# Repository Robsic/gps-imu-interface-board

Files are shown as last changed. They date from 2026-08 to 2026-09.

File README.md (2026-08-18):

# Placa GPS/IMU e interface de encoders — RobSIC

Placa de aquisição e comunicação para o carrinho elétrico RobSIC, baseada em módulo STM32F103/Blue Pill. O hardware integra alimentação de 12 V, interface CAN, duas entradas de encoder incremental diferencial A/B/Z, conexão para módulo IMU, conexão para módulo GPS e interfaces de programação/depuração.

> **Status:** projeto em desenvolvimento e **não liberado para fabricação**. O relatório DRC fornecido registra 20 violações: 12 de máscara de solda, 5 de clearance, 1 texto espelhado e 2 conflitos de silk sobre cobre.

> **Simulação funcional:** a integração GPS/NMEA, UART, pacote ACEINNA `e2`, CRC e estímulos de IMU/encoders foi exercitada no Proteus 9.1. CAN, desempenho dos sensores reais e comportamento elétrico permanecem pendentes de bancada.

## Arquitetura

```mermaid
flowchart TD
    PWR["12 V — J1"] --> DCDC["TSR2-2450 — 5 V"]
    DCDC --> LDO["LM1117-3.3 — 3,3 V"]
    LDO --> MCU["Blue Pill / STM32F103"]
    CAN["CANH/CANL — J1"] <-->|"SN65HVD230"| MCU
    ENC["2 encoders A/B/Z"] -->|"TVS + AM26LV32"| MCU
    MCU <-->|"UART"| IMU["Módulo IMU — J5"]
    IMU <-->|"UART2"| GPS["Módulo GPS — J4"]
```

## Simulação e validação no Proteus

O ensaio utiliza duas Blue Pills:

- `U1`: controlador principal da placa;
- `U2`: emulador funcional do OpenIMU300ZI;
- `VGPS`: fonte de mensagens NMEA;
- dois terminais virtuais para observar o NMEA a 9600 baud e o diagnóstico da U1 a 115200 baud.

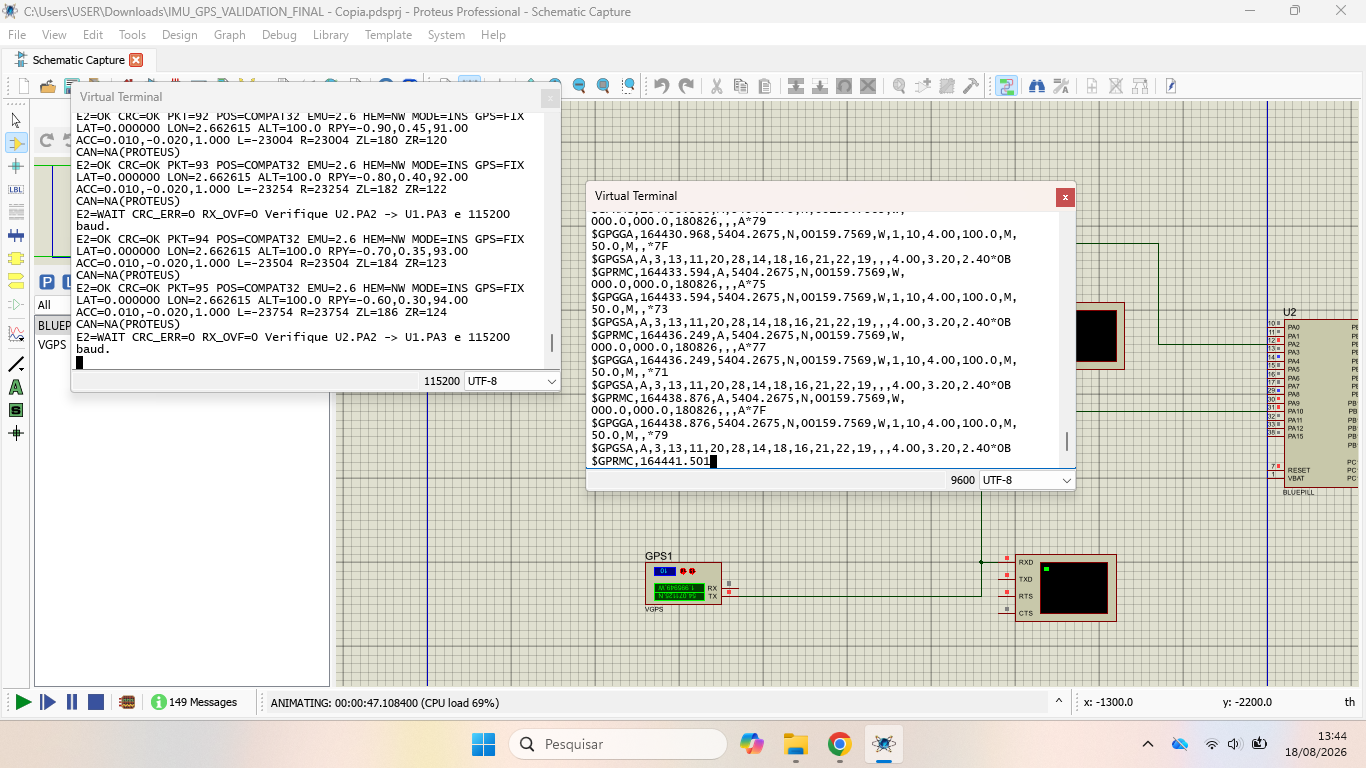
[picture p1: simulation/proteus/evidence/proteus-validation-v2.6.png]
Validação funcional no Proteus


Resultados confirmados na simulação:

- recepção das mensagens NMEA `GGA`, `RMC` e `GSA`;
- detecção de `GPS=FIX` e hemisférios `NW`;
- transmissão U2 → U1 a 115200 baud;
- recepção de pacotes ACEINNA `e2` com `CRC=OK`;
- contador de pacotes crescente, `CRC_ERR=0` e `RX_OVF=0`;
- transporte de dados sintéticos de orientação, aceleração e encoders.

Limitações conhecidas:

- a conversão decimal de latitude/longitude não é confiável no modelo VSM de terceiros da Blue Pill; as coordenadas NMEA de entrada estão corretas;
- o CAN não é suportado de forma confiável por esse modelo e aparece como `CAN=NA(PROTEUS)`;
- os dados de IMU e encoders são estímulos funcionais, não medições de sensores físicos.

Arquivos, firmware e procedimento completo: [simulação Proteus](simulation/proteus/README.md).

## Características extraídas dos arquivos

- KiCad: gerador `10.0`.
- Dimensão do contorno: `111 mm × 79 mm`.
- Componentes posicionados: 31.
- Roteamento: 415 segmentos e 50 vias.
- Alimentação de entrada nominal indicada: `+12 V`.
- Conversão: `TSR2-2450` para 5 V e `LM1117-3.3` para 3,3 V.
- CAN: `SN65HVD230`, com terminação de 120 Ω.
- Encoders: dois canais diferenciais A/B/Z, protegidos por `SRV05-4` e recebidos por `AM26LV32`.
- Controlador: módulo Blue Pill/STM32F103.

## Interfaces principais

| Conector | Função | Resumo |
|---|---|---|
| J1 | Alimentação e CAN | `+12 V`, `CANH`, `CANL`, `GND` |
| J2 | Encoder com nets `Esq` | `GND`, `+5 V`, pares diferenciais A/B/Z |
| J3 | Encoder com nets `Dir` | `GND`, `+5 V`, pares diferenciais A/B/Z |
| J4 | Módulo GPS | UART2, `+3.3V_GPS`, `GND` |
| J5 | Módulo IMU | UART, UART2 do GPS, SWD, reset, 3,3 V e GND |
| JTAG_IMU1 | Depuração da IMU | `NRST`, `SWDIO`, `SWCLK`; pino 4 está sem GND |

> Os valores visuais `J_Dir` e `J_Esq` estão trocados em relação aos nomes das redes do PCB: J2 carrega sinais `*_Esq` e J3 carrega sinais `*_Dir`. Use as redes e a tabela de pinagem como referência até corrigir a serigrafia/valor.

## Abrindo o projeto

1. Instale o KiCad 10 ou versão compatível mais recente.
2. Baixe a pasta completa, preservando todas as subpastas de footprints e `Kicad-STM32-master/`.
3. Abra `IMU_board.kicad_pro`.
4. Confira `fp-lib-table`; todas as entradas devem usar `${KIPRJMOD}` e caminhos relativos.
5. Corrija `sym-lib-table` antes de compartilhar: há referência a `${KIPRJMOD}/IMU_GPS_Blue_Pill/...` e um caminho absoluto `/home/ryan/...`, que não são portáveis na estrutura atual.
6. Abra as folhas hierárquicas `IMU.kicad_sch`, `GPS.kicad_sch` e `stm32f103.kicad_sch` pelo esquema principal.
7. Execute ERC e DRC novamente; não gere Gerbers enquanto houver violações.

## Estrutura recomendada para o GitHub

```text
gps-imu-interface-board/
├── README.md
├── BOM.csv
├── .gitignore
├── hardware/
│   ├── IMU_board.kicad_pro
│   ├── IMU_board.kicad_sch
│   ├── IMU_board.kicad_pcb
│   ├── GPS.kicad_sch
│   ├── IMU.kicad_sch
│   ├── stm32f103.kicad_sch
│   ├── fp-lib-table
│   ├── sym-lib-table
│   └── libraries/
├── firmware/
├── docs/
│   ├── HARDWARE.md
│   ├── FIRMWARE.md
│   ├── VALIDATION.md
│   └── GITHUB.md
├── manufacturing/
└── legacy/
```

## Documentos

- [Hardware e pinagem](docs/HARDWARE.md)
- [Firmware e mapa do STM32](docs/FIRMWARE.md)
- [Validação e DRC](docs/VALIDATION.md)
- [Preparação e envio ao GitHub](docs/GITHUB.md)
- [Simulação funcional no Proteus 9.1](simulation/proteus/README.md)
- [Lista de materiais](BOM.csv)

## Pendências críticas

- eliminar as 20 violações do DRC fornecido;
- corrigir as bibliotecas com caminhos absolutos ou diretórios inexistentes;
- corrigir a identificação J2/J3;
- adicionar GND ao cabeçalho de programação da IMU ou documentar ponto de referência externo;
- confirmar o footprint polarizado de C4, marcado como 100 nF;
- confirmar pinagem física dos módulos GPS e IMU com os respectivos datasheets;
- desenvolver o firmware de produção, configuração STM32CubeMX/CubeIDE e protocolo CAN; o firmware incluído em `simulation/` é exclusivo para validação funcional;
- validar entrada de 12 V e proteções para uso veicular;
- gerar pacote de fabricação somente depois da liberação.

## Licença

Nenhuma licença foi definida. Antes de tornar o repositório público, escolha licenças compatíveis para hardware, firmware, bibliotecas de terceiros e documentação.

## Responsável

Vinícius Corcínio Silva — projeto RobSIC.

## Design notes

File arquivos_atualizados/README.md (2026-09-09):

# Placa GPS/IMU e interface de encoders — RobSIC

Placa de aquisição e comunicação para o carrinho elétrico RobSIC, baseada em módulo STM32F103/Blue Pill. O hardware integra alimentação de 12 V, interface CAN, duas entradas de encoder incremental diferencial A/B/Z, conexão para módulo IMU, conexão para módulo GPS e interfaces de programação/depuração.

> **Status:** projeto em desenvolvimento e **não liberado para fabricação**. O relatório DRC fornecido registra 20 violações: 12 de máscara de solda, 5 de clearance, 1 texto espelhado e 2 conflitos de silk sobre cobre.

> **Simulação funcional:** a integração GPS/NMEA, UART, pacote ACEINNA `e2`, CRC e estímulos de IMU/encoders foi exercitada no Proteus 9.1. CAN, desempenho dos sensores reais e comportamento elétrico permanecem pendentes de bancada.

> **Atualização de hardware — 09/09/2026:** esquemático e PCB atualizados com conectores Molex Micro-Fit 3.0, biblioteca local de footprints e referências portáveis via `${KIPRJMOD}`.

## Arquitetura

```mermaid
flowchart TD
    PWR["12 V — J1"] --> DCDC["TSR2-2450 — 5 V"]
    DCDC --> LDO["LM1117-3.3 — 3,3 V"]
    LDO --> MCU["Blue Pill / STM32F103"]
    CAN["CANH/CANL — J1"] <-->|"SN65HVD230"| MCU
    ENC["2 encoders A/B/Z"] -->|"TVS + AM26LV32"| MCU
    MCU <-->|"UART"| IMU["Módulo IMU — J5"]
    IMU <-->|"UART2"| GPS["Módulo GPS — J4"]
```

## Simulação e validação no Proteus

O ensaio utiliza duas Blue Pills:

- `U1`: controlador principal da placa;
- `U2`: emulador funcional do OpenIMU300ZI;
- `VGPS`: fonte de mensagens NMEA;
- dois terminais virtuais para observar o NMEA a 9600 baud e o diagnóstico da U1 a 115200 baud.

Validação funcional no Proteus

Resultados confirmados na simulação:

- recepção das mensagens NMEA `GGA`, `RMC` e `GSA`;
- detecção de `GPS=FIX` e hemisférios `NW`;
- transmissão U2 → U1 a 115200 baud;
- recepção de pacotes ACEINNA `e2` com `CRC=OK`;
- contador de pacotes crescente, `CRC_ERR=0` e `RX_OVF=0`;
- transporte de dados sintéticos de orientação, aceleração e encoders.

Limitações conhecidas:

- a conversão decimal de latitude/longitude não é confiável no modelo VSM de terceiros da Blue Pill; as coordenadas NMEA de entrada estão corretas;
- o CAN não é suportado de forma confiável por esse modelo e aparece como `CAN=NA(PROTEUS)`;
- os dados de IMU e encoders são estímulos funcionais, não medições de sensores físicos.

Arquivos, firmware e procedimento completo: [simulação Proteus](simulation/proteus/README.md).

## Características extraídas dos arquivos

- KiCad: gerador `10.0`.
- Dimensão do contorno: `111 mm × 79 mm`.
- Componentes posicionados: 31.
- Roteamento: 415 segmentos e 50 vias.
- Alimentação de entrada nominal indicada: `+12 V`.
- Conversão: `TSR2-2450` para 5 V e `LM1117-3.3` para 3,3 V.
- CAN: `SN65HVD230`, com terminação de 120 Ω.
- Encoders: dois canais diferenciais A/B/Z, protegidos por `SRV05-4` e recebidos por `AM26LV32`.
- Controlador: módulo Blue Pill/STM32F103.

## Interfaces principais

| Conector | Função | Resumo |
|---|---|---|
| J1 | Alimentação e CAN | `+12 V`, `CANH`, `CANL`, `GND` |
| J2 | Encoder com nets `Esq` | `GND`, `+5 V`, pares diferenciais A/B/Z |
| J3 | Encoder com nets `Dir` | `GND`, `+5 V`, pares diferenciais A/B/Z |
| J4 | Módulo GPS | UART2, `+3.3V_GPS`, `GND` |
| J5 | Módulo IMU | UART, UART2 do GPS, SWD, reset, 3,3 V e GND |
| JTAG_IMU1 | Depuração da IMU | `NRST`, `SWDIO`, `SWCLK`; pino 4 está sem GND |

> Os valores visuais `J_Dir` e `J_Esq` estão trocados em relação aos nomes das redes do PCB: J2 carrega sinais `*_Esq` e J3 carrega sinais `*_Dir`. Use as redes e a tabela de pinagem como referência até corrigir a serigrafia/valor.

## Abrindo o projeto

1. Instale o KiCad 10 ou versão compatível mais recente.
2. Baixe a pasta completa, preservando todas as subpastas de footprints e `Kicad-STM32-master/`.
3. Abra `IMU_board.kicad_pro`.
4. Confira `fp-lib-table`; todas as entradas devem usar `${KIPRJMOD}` e caminhos relativos.
5. Confirme que `sym-lib-table` e `fp-lib-table` foram carregados como bibliotecas específicas do projeto; as referências incluídas já usam caminhos relativos via `${KIPRJMOD}`.
6. Abra as folhas hierárquicas `IMU.kicad_sch`, `GPS.kicad_sch` e `stm32f103.kicad_sch` pelo esquema principal.
7. Execute ERC e DRC novamente; não gere Gerbers enquanto houver violações.

O modelo 3D local da Blue Pill usa o arquivo WRL versionado. O STEP completo, com 92,6 MB, permanece na pasta de origem do Google Drive para evitar inflar o repositório.

## Estrutura recomendada para o GitHub

```text
gps-imu-interface-board/
├── README.md
├── BOM.csv
├── .gitignore
├── hardware/
│   ├── IMU_board.kicad_pro
│   ├── IMU_board.kicad_sch
│   ├── IMU_board.kicad_pcb
│   ├── GPS.kicad_sch
│   ├── IMU.kicad_sch
│   ├── stm32f103.kicad_sch
│   ├── fp-lib-table
│   ├── sym-lib-table
│   └── libraries/
├── firmware/
├── docs/
│   ├── HARDWARE.md
│   ├── FIRMWARE.md
│   ├── VALIDATION.md
│   └── GITHUB.md
├── manufacturing/
└── legacy/
```

## Documentos

- [Hardware e pinagem](docs/HARDWARE.md)
- [Firmware e mapa do STM32](docs/FIRMWARE.md)
- [Validação e DRC](docs/VALIDATION.md)
- [Preparação e envio ao GitHub](docs/GITHUB.md)
- [Portabilidade e bibliotecas locais do KiCad](docs/KICAD_PORTABILITY.md)
- [Documentação técnica original da placa](DOCUMENTACAO_GPS.md)
- [Simulação funcional no Proteus 9.1](simulation/proteus/README.md)
- [Lista de materiais](BOM.csv)

## Pendências críticas

- eliminar as 20 violações do DRC fornecido;
- corrigir a identificação J2/J3;
- adicionar GND ao cabeçalho de programação da IMU ou documentar ponto de referência externo;
- confirmar o footprint polarizado de C4, marcado como 100 nF;
- confirmar pinagem física dos módulos GPS e IMU com os respectivos datasheets;
- desenvolver o firmware de produção, configuração STM32CubeMX/CubeIDE e protocolo CAN; o firmware incluído em `simulation/` é exclusivo para validação funcional;
- validar entrada de 12 V e proteções para uso veicular;
- gerar pacote de fabricação somente depois da liberação.

## Licença

Nenhuma licença foi definida. Antes de tornar o repositório público, escolha licenças compatíveis para hardware, firmware, bibliotecas de terceiros e documentação.

## Responsável

Vinícius Corcínio Silva — projeto RobSIC.

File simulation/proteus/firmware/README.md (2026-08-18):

# Firmware exclusivo para simulação

Estes programas foram escritos para validar a comunicação no Proteus e não são o firmware final do veículo.

## Alvos

- `u1_main`: recebe o pacote ACEINNA `e2`, valida CRC, extrai os campos, exercita as entradas de encoder e imprime o diagnóstico.
- `u2_openimu_emulator`: recebe NMEA do `VGPS`, produz dados sintéticos de IMU e transmite o pacote `e2`.

## Compilação

Requisitos:

- GNU Make;
- toolchain `arm-none-eabi-gcc`;
- GCC nativo para os testes do computador.

O prefixo da toolchain pode ser informado por `TOOLCHAIN`:

```bash
make -C u1_main TOOLCHAIN=arm-none-eabi-
make -C u2_openimu_emulator TOOLCHAIN=arm-none-eabi-
gcc -std=c11 -O2 -Wall -Wextra -Werror tests/fixed_ieee_test.c -o /tmp/fixed_ieee_test
/tmp/fixed_ieee_test
```

Os HEX previamente gerados e utilizados na evidência estão em `hex/`.

## Protocolo

O pacote oficial `e2` utiliza:

- preâmbulo `0x55 0x55`;
- código `0x65 0x32`;
- payload de 123 bytes;
- valores multibyte do payload em little-endian;
- CRC16-CCITT, polinômio `0x1021`, valor inicial `0x1D0F` e sem XOR final.

A versão 2.6 também envia o pacote auxiliar `c6` para diagnóstico do emulador. Ele não altera o pacote oficial `e2`.

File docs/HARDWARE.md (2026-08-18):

# Hardware e interfaces

## Visão geral

A placa integra:

- entrada nominal de 12 V;
- conversores para 5 V e 3,3 V;
- Blue Pill/STM32F103;
- transceiver CAN SN65HVD230;
- duas interfaces diferenciais A/B/Z para encoders;
- conectores para GPS e OpenIMU300ZI;
- interfaces de programação e depuração.

## Conectores

| Conector | Função |
|---|---|
| `J1` | alimentação, GND, CANH e CANL |
| `J2` | encoder associado às redes `*_Esq` |
| `J3` | encoder associado às redes `*_Dir` |
| `J4` | GPS, alimentação e UART |
| `J5` | IMU, UARTs, SWD, reset e alimentação |
| `JTAG_IMU1` | SWD da IMU |

Os textos visuais `J_Dir` e `J_Esq` precisam ser conferidos: os nomes de rede indicam J2 como esquerdo e J3 como direito.

## Pinos principais do STM32

| Função | Pino |
|---|---|
| Encoder esquerdo A/B | `PA0/PA1` |
| Comunicação principal com IMU | `PA2/PA3` |
| Encoder direito A/B | `PB6/PB7` |
| Índices esquerdo/direito | `PB8/PB9` |
| CAN RX/TX | `PA11/PA12` |

## Estado de fabricação

O relatório DRC arquivado contém 20 ocorrências e a placa ainda não deve ser tratada como liberada para fabricação. Consulte [VALIDATION.md](VALIDATION.md).

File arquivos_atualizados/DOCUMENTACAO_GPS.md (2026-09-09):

# Documentação Técnica — Placa GPS-IMU (Robsic)

> Documentação detalhada do funcionamento da placa integrada **GPS-IMU**, projeto
> `IMU_GPS_Blue_Pill`, desenvolvido em KiCad. Esta placa integra um módulo **GPS**,
> uma **IMU OpenIMU300ZI**, um microcontrolador **STM32F103 (Blue Pill)**, um
> **regulador de tensão LM1117-3.3** e um **transceiver CAN SN65HVD230**.

---

## 1. Introdução & Visão Geral

A placa GPS-IMU foi projetada para atuar como nó de aquisição inercial e de
posicionamento em um sistema embarcado maior (carrinho Robsic). Ela concentra,
em uma única PCB, os seguintes subsistemas:

- **Posicionamento** — receptor GPS conectado ao microcontrolador via UART2.
- **Atitude/Movimento** — IMU OpenIMU300ZI (Aceinna) conectada via UART.
- **Processamento** — STM32F103 (módulo Blue Pill).
- **Comunicação externa** — barramento CAN (transceiver SN65HVD230).
- **Alimentação** — regulador linear LM1117-3.3 que converte 12 V → 3,3 V.

### Representação 2D e 3D da placa

<p align="left" width="100%">
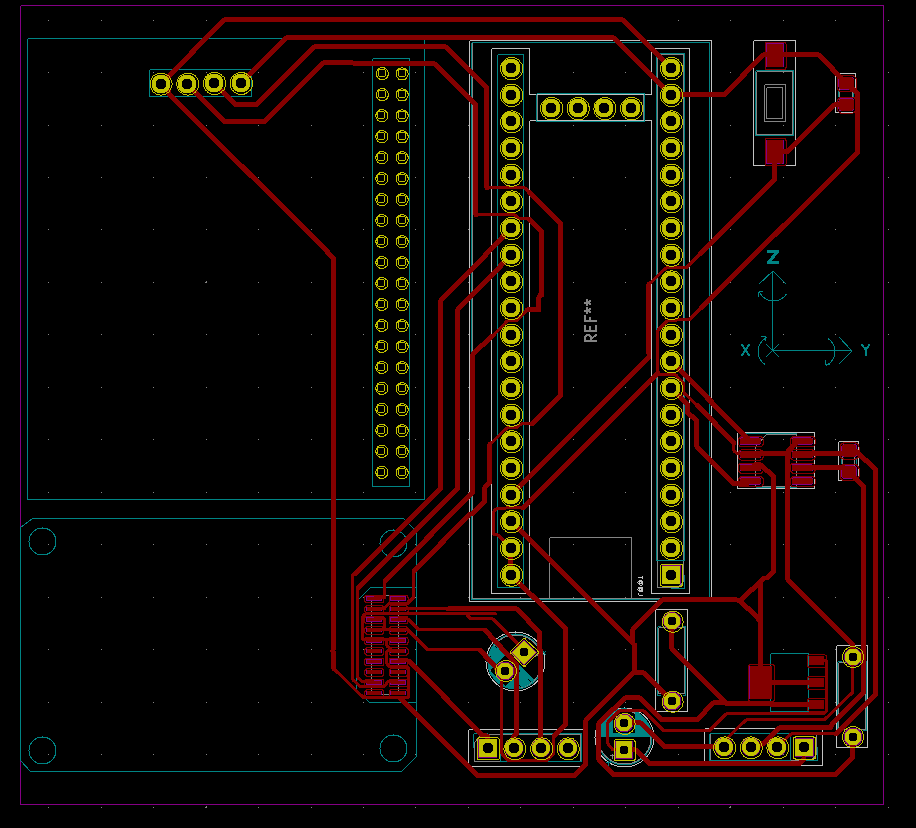
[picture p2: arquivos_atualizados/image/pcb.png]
  
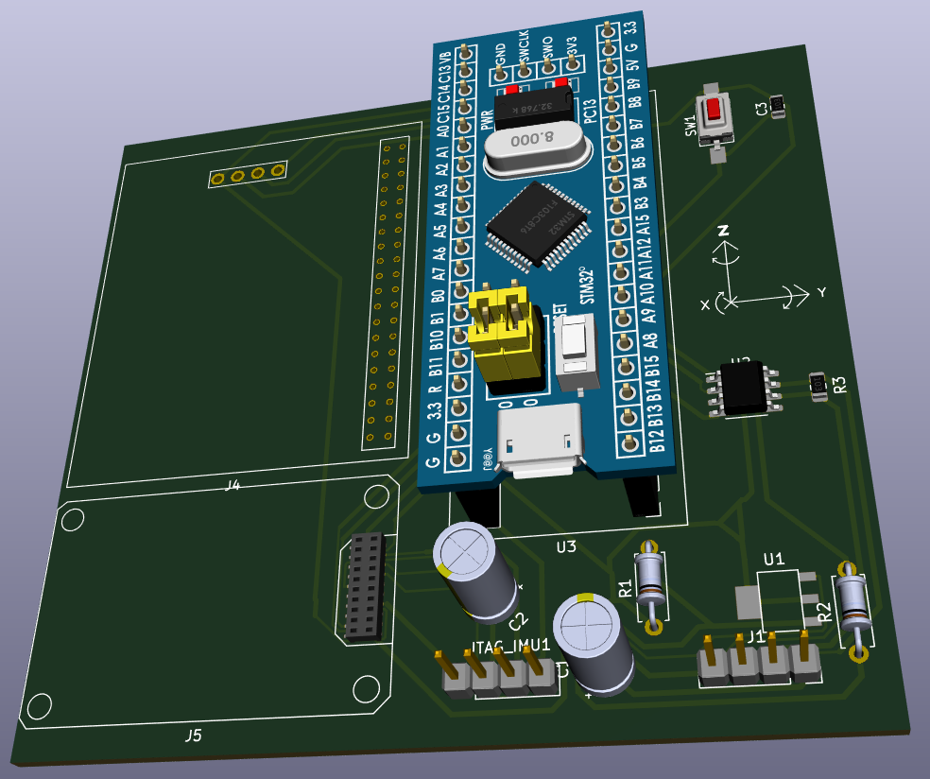
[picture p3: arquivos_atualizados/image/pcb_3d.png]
  
</p>

---

## 2. Arquitetura do Sistema

### Diagrama de blocos

```
                +-----------+                      +--------------------+
                |   GPS J4  |  UART2 (tx/rx)       |  STM32F103         |
                | 2x20 fêmea|  ------------------>  |  (Blue Pill U3)    |
                +-----------+                      +--------------------+
                                                         |     |
                                          UART           |     | CAN (tx/rx)
                                +--------------------+   |     |
                                |  IMU OpenIMU300ZI  |<--+     v
                                |      J5 (2x10)     |   +--------------------+
                                +--------------------+   |  SN65HVD230 (U2)   |
                                                         +--------------------+
                                                              |     |
                                                              v     v
                                                           canH    canL
                                                          (barramento CAN)

   Alimentação:
   +------+      +--------------+      +-------+
   | 12V  | ---> | LM1117-3.3   | ---> | 3,3V  | ---> GPS, IMU, STM32, CAN
   +------+      | (U1)         |      +-------+
                 +--------------+
                 C1 (10uF) entrada | C2 (100uF) saída | R1 (1k) / R2 (620 Ohm) feedback
```

### Hierarquia de esquemas (KiCad)

O projeto `IMU_board.kicad_pro` é dividido em 4 _sheets_:

| Sheet | Arquivo | Função |
|---|---|---|
| 1/4 | `IMU_board.sch` | Esquema raiz: regulador, CAN, conectores |
| 2/4 | `IMU.sch` | Sub-esquema da IMU (J5) e JTAG |
| 3/4 | `GPS.sch` | Sub-esquema do GPS (J4) |
| 4/4 | `stm32f103.sch` | Sub-esquema do STM32 (Blue Pill) |

---

## 3. Componentes Principais

### 3.1 GPS — Conector fêmea 2x20 (J4)

- **Referência:** `Conn_02x20_Top_Bottom` (J4)
- **Footprint:** `conn_gps_female_2x20:conn_gps_female_2x20`
  (footprint customizado, 40 pinos + 4 furos de montagem)
- **Alimentação:** +3,3 V (pino 4) e GND (pino 40)
- **Comunicação:** UART2 com o STM32
  - `uart2_tx_out_gps` — TX do GPS → RX do STM32 (UART2)
  - `uart2_rx_in_gps`  — TX do STM32 (UART2) → RX do GPS
- **Imagem de referência:** `image/gps.jpg`

### 3.2 IMU — OpenIMU300ZI (Aceinna)

- **Referência:** Conector 2x10 `Conn_02x10_Odd_Even` (J5)
- **Footprint:** `imu_connector_female_2x10:imu_connector_female_2x10`
- **Alimentação:** +3,3 V e GND
- **Comunicação principal:** UART com o STM32
  - `uart_tx_out_imu` — TX da IMU → RX do STM32
  - `uart_rx_in_imu`  — TX do STM32 → RX da IMU
- **Debug/Programação:** conector JTAG `JTAG_IMU1` (1x04, PinSocket 2,54 mm)
  - `swdio_imu`, `swclk_imu`, `nrst_imu`
- **Documentação oficial:**
  - https://www.aceinna.com/openimu
  - https://www.aceinna.com/inertial-systems/OpenIMU300ZI
- **Imagem de referência:** `image/imu.png`

### 3.3 MCU — STM32F103 (Blue Pill, U3)

- **Referência:** `YAAJ_BluePill_Part_Like_SWD_Breakout` (U3)
- **Footprint:** `Blue_pill:YAAJ_BluePill_SWD_2`
- **Biblioteca de símbolos:** `Kicad-STM32-master` (YAAJ)
- **Reset:** botão `SW1` (FSMSM) + capacitor `C3` (100 nF) para debounce
  — sinal `nrst`
- **Interfaces usadas:**
  - **UART2** — comunicação com o GPS
  - **UART** — comunicação com a IMU
  - **CAN** — `can_tx` / `can_rx` para o transceiver SN65HVD230
- **Alimentação:** +3,3 V e GND

### 3.4 Regulador de Tensão — LM1117-3.3 (U1)

- **Referência:** `componentes:LM1117-3.3` (U1)
- **Footprint:** `LM117IMPX3.3:LM1117IMP_3.3_NOPB`
- **Fabricante:** Texas Instruments
- **Função:** regulador linear LDO que converte a tensão de entrada `vcc_12`
  (12 V) para +3,3 V, alimentando todos os subsistemas da placa.
- **Circuito de suporte:**
  - **C1** — 10 µF (radial, P2,50 mm) — capacitor de entrada
  - **C2** — 100 µF (radial, P2,50 mm) — capacitor de saída
  - **R1** — 1 kΩ (axial DIN0207) — divisor de feedback
  - **R2** — 620 Ω (axial DIN0207) — divisor de feedback
- **Esquema de referência:** fornecido pelo Texas Instruments no datasheet do
  LM1117.
- **Imagem de referência:** `image/voltage_regulator.png`

### 3.5 Transceiver CAN — SN65HVD230 (U2)

- **Referência:** `stm32f103:u_SN65HVD230` (U2)
- **Footprint:** `Package_SO:SOIC-8_3.9x4.9mm_P1.27mm`
- **MPN:** `SN65HVD230MDREP`
- **Fabricante:** Texas Instruments
- **Função:** converte os sinais lógicos `can_tx`/`can_rx` do STM32 em sinais
  diferenciais `canH`/`canL` para o barramento CAN.
- **Terminação:** resistor **R3** de 120 Ω
  (`ERJ-P06F1200V`, SMD 0805) — terminação do barramento CAN.
- **Alimentação:** +3,3 V (pino VCC) e GND
- **Datasheet:** http://www.ti.com/lit/ds/symlink/sn65hvd230.pdf

---

## 4. Glossário de Sinais

| Sinal | Direção | Roteamento (Origem → Destino) | Sub-esquema  |
|---|---|---|---|
| `uart2_tx_out_gps`  | Saída | GPS (J4) → STM32 (UART2 RX) | GPS.sch |
| `uart2_rx_in_gps` | Entrada | STM32 (UART2 TX) → GPS (J4) | GPS.sch |
| `uart_tx_out_imu` | Saída | STM32 → IMU (J5) | stm32f103.sch|
| `uart_rx_in_imu` | Entrada | IMU (J5) → STM32 | stm32f103.sch|
| `can_tx` | Saída | STM32 → SN65HVD230 (U2) | stm32f103.sch|
| `can_rx` | Entrada | SN65HVD230 (U2) → STM32 | stm32f103.sch|
| `canH` | Saída | SN65HVD230 → barramento CAN | IMU_board.sch|
| `canL` | Saída | SN65HVD230 → barramento CAN | IMU_board.sch|
| `vcc_12` | Pot. | Fonte externa (12 V) → LM1117 | IMU_board.sch|
| `+3.3V` | Pot. | LM1117 saída → GPS, IMU, STM32, CAN | todos |
| `GND` | Pot. | Referência comum | todos |
| `swdio_imu` | I/O | Debug IMU (JTAG_IMU1) | IMU.sch |
| `swclk_imu` | Saída  | Clock debug IMU (JTAG_IMU1) | IMU.sch |
| `nrst_imu` | Saída  | Reset debug IMU (JTAG_IMU1) | IMU.sch |
| `nrst` | I/O | Reset do STM32 (SW1 + C3) | stm32f103.sch|

> **Convenção de nomenclatura:** os sinais seguem o padrão
> `<interface>_<direção>_<destino>`. Por exemplo, `uart2_tx_out_gps` indica
> o pino TX da UART2 que sai do STM32 em direção ao GPS.

---

## 5. Fluxo de Comunicação

### 5.1 GPS ↔ STM32 (UART2)

```
   GPS (J4)                        STM32 (Blue Pill U3)
   --------                        --------------------
   pino 29 (uart2_tx_out_gps) ---> UART2_RX (entrada)
   pino 30 (uart2_rx_in_gps)  <--- UART2_TX (saída)
```

O GPS envia sentenças NMEA (ou dados binários) pela UART2 ao STM32, que por
sua vez pode enviar comandos de configuração de volta ao GPS.

### 5.2 STM32 ↔ IMU OpenIMU300ZI (UART)

```
   STM32 (Blue Pill U3)            IMU (J5)
   -----------------------         ---------
   uart_tx_out_imu  ------------>  uart_rx_in_imu
   uart_rx_in_imu   <------------  uart_tx_out_imu
```

A IMU envia quadros de dados inerciais (acelerômetro/giroscópio) ao STM32.
Programação/depuração ocorre via SWD (`swdio`, `swclk`, `nrst`) pelo conector
`JTAG_IMU1`.

### 5.3 STM32 ↔ Barramento CAN (via SN65HVD230)

```
   STM32 (U3)                     SN65HVD230 (U2)              Barramento CAN
   ----------                     ---------------              ---------------
   can_tx  ---------------------->  D   (TX)                     canH
   can_rx  <----------------------  R   (RX)                      canL
                                                     |
                                                R3 (120 Ω)  -- terminação
```

O STM32 envia frames CAN ao transceiver, que os converte em sinais
diferenciais `canH`/`canL`. Um resistor de terminação de 120 Ω (R3) é
previsto na placa.

### 5.4 Seletor de Interface — Pino 7 (UART/SPI)

Conforme observações do projeto, o **pino 7** do conector IMU atua como
seletor de interface de comunicação entre **UART** e **SPI**. Consulte a
imagem `image/obs.png` para detalhes de configuração do jumper/seleção.

---

## 6. Alimentação

### Topologia de potência

```
            +-------------------+
   12 V --->|  Entrada          |   C1 (10 µF)        C2 (100 µF)
   (vcc_12) |  LM1117-3.3 (U1)  |----||----+--------||----+---> +3,3 V
            |                   |          |              |
            +-------------------+          GND            GND

   Divisor de feedback:  R1 (1 kΩ) --- R2 (620 Ω)  -> define a tensão de saída
```

### Distribuição dos 3,3 V

A saída +3,3 V do LM1117 alimenta diretamente:

| Subsistema | Componente | Pino de alimentação |
|---|---|---|
| GPS | J4 | Pino 4 (+3,3 V) |
| IMU | J5 | Pino de +3,3 V |
| STM32 | U3 (Blue Pill) | Pino +3,3 V |
| CAN | U2 (SN65HVD230) | Pino VCC (+3,3 V) |

A referência de terra comum (GND) é compartilhada por todos os subsistemas.

### Notas

- O esquema do regulador é baseado no circuito típico fornecido pela Texas
  Instruments no datasheet do LM1117.
- Os capacitores C1 e C2 garantem a estabilidade do LDO e devem ser
  posicionados próximos aos pinos de entrada/saída do U1.

---

## 7. Conectores & Pinagem

### 7.1 Conector GPS — J4 (2x20 Top/Bottom)

- **Referência:** `Conn_02x20_Top_Bottom` (J4)
- **Footprint:** `conn_gps_female_2x20`
- **Pinos ativos:** 4 (+3,3 V), 29 (TX), 30 (RX), 40 (GND)
- **Demais pinos:** não conectados (NoConn) conforme `GPS.sch`
- **Imagens de referência:** `image/interface_conn.png`,
  `image/info_pin_1.png`, `image/info_pin_2.png`

> Na convenção de pinos do conector 2x20, os **pinos ímpares** estão na
> coluna esquerda e os **pares** na direita. A numeração começa no topo.

| Pino | Função | Sinal / Tensão | Status |
|---|---|---|---|
| 1 | — | — | NoConn |
| 2 | — | — | NoConn |
| 3 | — | — | NoConn |
| **4**| **Alimentação** | **+3,3 V** | **Ativo** |
| 5 | — | — | NoConn |
| 6 | — | — | NoConn |
| 7 | Seletor UART/SPI | (configuração) | Ver obs.png |
| 8 | — | — | NoConn |
| 9 | — | — | NoConn |
| 10 | — | — | NoConn |
| 11 | — | — | NoConn |
| 12 | — | — | NoConn |
| 13 | — | — | NoConn |
| 14 | — | — | NoConn |
| 15 | — | — | NoConn |
| 16 | — | — | NoConn |
| 17 | — | — | NoConn |
| 18 | — | — | NoConn |
| 19 | — | — | NoConn |
| 20 | — | — | NoConn |
| 21 | — | — | NoConn |
| 22 | — | — | (montagem)  |
| 23 | — | — | NoConn |
| 24 | — | — | NoConn |
| 25 | — | — | NoConn |
| 26 | — | — | NoConn |
| 27 | — | — | NoConn |
| 28 | — | — | NoConn |
| **29**| **Comunicação** | **uart2_tx_out_gps** | **Ativo** |
| **30**| **Comunicação** | **uart2_rx_in_gps**  | **Ativo** |
| 31 | — | — | NoConn |
| 32 | — | — | NoConn |
| 33 | — | — | NoConn |
| 34 | — | — | NoConn |
| 35 | — | — | (montagem)  |
| 36 | — | — | NoConn |
| 37 | — | — | NoConn |
| 38 | — | — | NoConn |
| 39 | — | — | NoConn |
| **40**| **Alimentação** | **GND** | **Ativo** |

> Os pinos 22 e 35 correspondem aos furos de montagem do footprint
> `conn_gps_female_2x20` (diam. 1,0 mm), não são sinais funcionais.

### 7.2 Conector IMU — J5 (2x10 Odd/Even)

- **Referência:** `Conn_02x10_Odd_Even` (J5)
- **Footprint:** `imu_connector_female_2x10:imu_connector_female_2x10`

| Pino | Função | Sinal |
|---|---|---|
| — | Alimentação | +3,3 V |
| — | Referência | GND |
| — | RX da IMU | `uart_rx_in_imu` |
| — | TX da IMU | `uart_tx_out_imu` |
| — | SWDIO (debug) | `swdio_imu` |
| — | SWCLK (debug) | `swclk_imu` |
| — | Reset (debug) | `nrst_imu` |

> Para a correspondência exata de cada pino, consulte o símbolo do conector
> no esquema `IMU.sch` e a imagem `image/info_pin_1.png`.

### 7.3 Conector JTAG/Debug IMU — JTAG_IMU1 (1x04)

- **Referência:** `Conn_01x04` (JTAG_IMU1)
- **Footprint:** `Connector_PinSocket_2.54mm:PinSocket_1x04_P2.54mm_Vertical`

| Pino | Função | Sinal |
|---|---|---|
| 1 | Reset | `nrst_imu` |
| 2 | SWDIO | `swdio_imu`  |
| 3 | SWCLK | `swclk_imu`  |
| 4 | GND | GND |

### 7.4 Conector de Saída CAN — J1 (1x04)

- **Referência:** `Conn_01x04` (J1)
- **Footprint:** `Connector_PinSocket_2.54mm:PinSocket_1x04_P2.54mm_Vertical`

| Pino | Função | Sinal / Tensão |
|---|---|---|
| 1 | Alimentação  | `vcc_12` (12 V)|
| 2 | CAN High | `canH` |
| 3 | CAN Low | `canL` |
| 4 | Referência | GND |

---

## 8. Observações & Notas de Aplicação

### 8.1 Seletor de Interface UART/SPI (Pino 7)

O **pino 7** do conector IMU atua como seletor de interface de comunicação.
Quando configurado adequadamente, permite alternar entre os modos **UART**
e **SPI**. Consulte a imagem `image/obs.png` para detalhes de configuração.

### 8.2 Conexão das Portas Seriais

- **UART2** do STM32 é dedicada à comunicação com o **GPS**.
- A **UART principal** do STM32 é dedicada à comunicação com a **IMU**.
- Ambas operam em nível lógico **3,3 V** (compatibilidade direta com o
  STM32F103).

### 8.3 Barramento CAN

A comunicação externa da placa ocorre via barramento CAN, usando o
transceiver **SN65HVD230**`. Recomenda-se:

- Utilizar cabo par tranado para `canH`/`canL`.
- Garantir a terminação de 120 Ω em ambas as extremidades do barramento
  (o resistor **R3** já provê uma das terminações na placa).
- Tensão de alimentação do transceiver: 3,3 V.

### 8.4 Imagens de Referência Adicionais

| Imagem | Conteúdo |
|---|---|
| `image/obs.png` | Alimentação, portas seriais e seletor pin_7 |
| `image/type_comm.png` | Tipos de comunicação suportados |
| `image/info_pin_1.png` | Tabela de informações dos pinos (parte 1) |
| `image/info_pin_2.png` | Tabela de informações dos pinos (parte 2) |
| `image/interface_conn.png`| Conector de interface |

---

## 9. Referências

- **LM1117 — LDO Linear Regulator**, Texas Instruments:
  https://www.ti.com/product/LM1117
- **SN65HVD230 — CAN Transceiver**, Texas Instruments:
  http://www.ti.com/lit/ds/symlink/sn65hvd230.pdf
- **OpenIMU300ZI**, Aceinna:
  https://www.aceinna.com/inertial-systems/OpenIMU300ZI
- **OpenIMU (plataforma aberta)**, Aceinna:
  https://www.aceinna.com/openimu
- **STM32 Blue Pill (símbolos/footprints YAAJ)**, repositório
  `Kicad-STM32-master` incluído em `IMU_GPS_Blue_Pill/`.
- **Esquemas do projeto:** `IMU_GPS_Blue_Pill/IMU_board.kicad_pro`.

---

## 10. Mapa de Arquivos do Projeto

```
IMU_GPS_Blue_Pill/
├── IMU_board.kicad_pro          # arquivo de projeto KiCad (raiz)
├── IMU_board.kicad_sch          # esquema raiz (versão nova)
├── IMU_board.sch                # esquema raiz (versão legada)
├── IMU_board.kicad_pcb          # PCB
├── IMU.sch / IMU.kicad_sch      # sub-esquema IMU
├── GPS.sch                      # sub-esquema GPS
├── stm32f103.sch                # sub-esquema STM32
├── conn_gps_female_2x20.pretty/# footprint do conector GPS
├── RBS_stm32f103.pretty/        # footprints customizados (STM32, relé, step-down)
├── Kicad-STM32-master/          # biblioteca YAAJ Blue Pill
├── trilhas/                     # arquivos de roteamento (freerouting .dsn/.ses)
└── IMU_board-backups/           # backups datados do projeto
```

---

**Fim da documentação.** Para dúvidas sobre o projeto, consulte os esquemas
 `.sch` no KiCad ou entre em contato com a equipe Robsic.

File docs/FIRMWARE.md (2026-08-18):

# Firmware

## Estado atual

O repositório agora contém firmware de **simulação funcional** em [`simulation/proteus/firmware`](../simulation/proteus/firmware/README.md). Ele valida comunicação, protocolo e lógica de teste, mas não deve ser confundido com o firmware de produção do veículo.

Ainda é necessário criar e versionar o firmware de produção, contendo:

- projeto STM32CubeIDE, CMake ou equivalente;
- configuração de clock e periféricos;
- driver real do OpenIMU300ZI;
- recepção e conversão GPS no STM32 físico;
- timers e interrupções para os encoders;
- CAN com identificadores, escalas, heartbeat e estados de falha;
- watchdog, brownout, timeouts e inicialização segura;
- procedimento de build, gravação e depuração;
- testes unitários e de integração.

## Mapa funcional

| Função | Pino STM32 | Direção |
|---|---|---|
| Encoder esquerdo A | `PA0` | entrada |
| Encoder esquerdo B | `PA1` | entrada |
| IMU UART TX | `PA2` | saída |
| IMU UART RX | `PA3` | entrada |
| Encoder direito A | `PB6` | entrada |
| Encoder direito B | `PB7` | entrada |
| Encoder esquerdo Z | `PB8` | entrada |
| Encoder direito Z | `PB9` | entrada |
| CAN RX | `PA11` | entrada |
| CAN TX | `PA12` | saída |

O arquivo legado `IMU_board_.bin` não possui origem e versão suficientemente documentadas; não deve ser usado como firmware de produção sem rastreabilidade.

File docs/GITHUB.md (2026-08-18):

# Fluxo de contribuição

## Clonar

```bash
git clone https://github.com/Robsic/gps-imu-interface-board.git
cd gps-imu-interface-board
```

## Atualizar uma branch

```bash
git switch main
git pull --ff-only origin main
git switch -c nome-da-alteracao
```

Faça as alterações, confira `git status` e execute os testes aplicáveis.

```bash
git add .
git commit -m "Descrição objetiva da alteração"
git push -u origin nome-da-alteracao
```

Depois, abra o repositório no GitHub, selecione **Compare & pull request**, revise os arquivos e crie o pull request para `main`.

Não envie senhas, chaves, arquivos temporários ou backups automáticos.

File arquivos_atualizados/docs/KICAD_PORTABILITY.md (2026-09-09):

# Portabilidade do projeto KiCad — Placa IMU + GPS com Blue Pill (STM32)

Projeto KiCad (`IMU_board.kicad_sch` / `IMU_board.kicad_pcb`) para placa de IMU/GPS baseada em **OpenIMU300ZI** + **STM32 Blue Pill** + regulador **LM1117-3.3**.
Este README torna o projeto **portável para `git clone`** (sem dependências globais) e documenta as bibliotecas locais.

> Projeto pai: [`../README.md`](../README.md) · Datasheets: [`../Imu datasheet connector/`](../Imu%20datasheet%20connector/) · Biblioteca STM32: [`../Kicad-STM32-master/`](../Kicad-STM32-master/)

---

## 1. Estrutura e bibliotecas locais

Todas as libs não-padrão já estão **dentro do diretório do projeto** e são referenciadas via `${KIPRJMOD}` (pasta do `IMU_board.kicad_pro`). Após `git clone` o KiCad carrega automaticamente.

```text
gps-imu-interface-board/
├── sym-lib-table          # 4 libs Legacy via ${KIPRJMOD}
├── fp-lib-table           # 4 libs KiCad via ${KIPRJMOD}
├── Kicad-STM32-master/    # YAAJ BluePill/BlackPill — symbols + footprints + 3D
│   ├── Symbols/YAAJ_BluePill_Part_Like_SWD_Breakout.lib
│   ├── Footprints/
│   ├── LM1117IMPX-3.3_NOPB(1)/   # footprint do LM1117-3.3 (nome com parênteses)
│   └── Packages3d/
├── imu_connector_female_2x10.pretty/   # conector IMU 2×10 fêmea
├── conn_gps_female_2x20.pretty/        # conector GPS 2×20 fêmea
├── RBS_stm32f103.pretty/                # footprint RBS STM32F103 (alternativo)
├── conn_02x10_top_bottom_imu.lib       # símbolo conector IMU 2×10
├── imu_conector.lib / imu_conector.dcm # símbolo conector IMU (legado)
├── RBS_stm32f103.lib / .dcm             # símbolo STM32F103RET6 (legado)
├── rbs02_components.lib                 # BD-STM32-AD etc.
└── IMU_board-cache.lib                  # cache legado (mantido p/ compatibilidade)
```

### sym-lib-table (corrigido para relativo)

```lisp
(lib (name "imu_conn") (type "Legacy") (uri "${KIPRJMOD}/conn_02x10_top_bottom_imu.lib") ...)
(lib (name "Blue_pill") (type "Legacy") (uri "${KIPRJMOD}/Kicad-STM32-master/Symbols/YAAJ_BluePill_Part_Like_SWD_Breakout.lib") ...)
(lib (name "YAAJ_BluePill_Part_Like_SWD_Breakout") (type "Legacy") (uri "${KIPRJMOD}/Kicad-STM32-master/Symbols/YAAJ_BluePill_Part_Like_SWD_Breakout.lib") ...)
(lib (name "IMU_board-cache") (type "Legacy") (uri "${KIPRJMOD}/IMU_board-cache.lib") ...)
```

Antes havia `IMU_GPS_Blue_Pill/` duplicado em `imu_conn` e caminho absoluto `/home/ryan/.../IMU_board-cache.lib` — agora relativo.

### fp-lib-table

```lisp
(lib (name "Blue_pill") (type "KiCad") (uri "${KIPRJMOD}/Kicad-STM32-master/Footprints") ...)
(lib (name "LM117IMPX3.3") (type "KiCad") (uri "${KIPRJMOD}/Kicad-STM32-master/LM1117IMPX-3.3_NOPB(1)") ...)
(lib (name "imu_connector_female_2x10") (type "KiCad") (uri "${KIPRJMOD}/imu_connector_female_2x10.pretty") ...)
(lib (name "conn_gps_female_2x20") (type "KiCad") (uri "${KIPRJMOD}/conn_gps_female_2x20.pretty") ...)
```

> **Aviso nome com `()`**: `LM1117IMPX-3.3_NOPB(1)` contém parênteses. Funciona, mas pode quebrar scripts `git` em Windows. Se der erro, renomeie a pasta para `LM1117IMPX-3.3_NOPB_1` e atualize `fp-lib-table:4`.

---

## 2. Como usar após `git clone` — zero configuração

**Requisitos:** KiCad 7+ (testado 10.0.4).

```bash
git clone https://github.com/Robsic/gps-imu-interface-board.git
cd gps-imu-interface-board
kicad IMU_board.kicad_pro   # ou File → Open Project
```

O KiCad carrega `sym-lib-table` / `fp-lib-table` locais automaticamente (`Preferences → Manage Symbol/Footprint Libraries → Project Specific`).

- Não mexa em `Kicad-STM32-master/` — já é a lib YAAJ oficial (GitHub `yet-another-average-joe/Kicad-STM32`).
- `IMU_board.kicad_pcb` e conectores `2×10` / `2×20` resolvem sem instalação global.

**PCB não foi alterado eletricamente** nesta migração (só `sym-lib-table:3,6`). Resíduos `D:/Users/admin/...` em `Kicad-STM32-master/Footprints/*.kicad_mod:114` e `IMU_board.kicad_pcb:6957` são legados do YAAJ e não afetam fabricação.

---

## 3. Adicionar nova biblioteca (ex.: Molex / Bourns para bornes)

Para manter o padrão de `treadle` e `Steer/Estercamento`:

```bash
cp -a /home/ryan/Documentos/Robsic\ Carrinho/pedais/treadle/libs/Connector_Molex ./libs/Connector_Molex
# em fp-lib-table adicione:
# (lib (name "Connector_Molex") (type "KiCad") (uri "${KIPRJMOD}/libs/Connector_Molex/Connector_Molex.pretty") ...)
git add libs/Connector_Molex fp-lib-table
```

Mapeamento Molex usado nos outros projetos (se precisar aqui):
- 2 pinos → `Connector_Molex:Molex_Micro-Fit_3.0_Molex_Micro-Fit_3.0_Header_Vertical_1x02_P3.00mm_Snap-in_Plastic_Peg_TH_436500215` (fallback genérico `...1x02...`)
- 3 pinos → `...1x03...436500315`
- 4 pinos → `...1x04...436500415`

---

## 4. Primeiro `git push` (se ainda não é repo)

```bash
cd IMU_GPS_Blue_Pill
git init
git add sym-lib-table fp-lib-table Kicad-STM32-master/ *.pretty/ *.lib *.dcm IMU_board.kicad_* README.md .gitignore
git status  # confirme: grep -r "/home/ryan" sym-lib-table_fp-lib-table deve ser vazio
git commit -m "fix: torna sym-lib-table portável via \${KIPRJMOD} e documenta libs locais"
git branch -M main && git remote add origin <URL> && git push -u origin main
```

`.gitignore` já ignora `*.lck`, `*-backups/`, `fp-info-cache`.

---

## 5. Checklist de portabilidade

- [ ] `grep -r "/home/ryan" sym-lib-table fp-lib-table` vazio
- [ ] `ls Kicad-STM32-master/Symbols/YAAJ_BluePill_Part_Like_SWD_Breakout.lib` existe
- [ ] Abrir `IMU_board.kicad_sch` → ERC 0 erros de lib
- [ ] Abrir `IMU_board.kicad_pcb` → DRC sem "missing footprint"

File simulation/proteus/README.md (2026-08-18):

# Simulação funcional GPS + OpenIMU + Blue Pill

Esta pasta reúne o ensaio realizado no Proteus 9.1 para validar a cadeia digital do projeto:

```text
VGPS (NMEA) -> U2 (emulador OpenIMU300ZI) -> pacote ACEINNA e2 -> U1 -> diagnóstico
```

O ensaio não substitui a validação elétrica da placa. A segunda Blue Pill é apenas um emulador funcional do OpenIMU300ZI e os encoders são estimulados por loopback.

- data da evidência: 18/08/2026;
- ambiente usado: Proteus Professional 9.1, 64 bits;
- requisito local: componente VSM `BLUEPILL` devidamente instalado e componente nativo `VGPS`.

Bibliotecas ou instaladores de terceiros não são redistribuídos neste repositório.

## Conteúdo

| Caminho | Finalidade |
|---|---|
| `IMU_GPS_VALIDATION_BASE.pdsprj` | Projeto-base do Proteus com o componente Blue Pill |
| `firmware/hex/bluepill_main_aceinna_e2_v2_6.hex` | Firmware da U1 |
| `firmware/hex/openimu300zi_emulator_v2_6.hex` | Firmware da U2 |
| `firmware/u1_main/` | Código-fonte e Makefile da U1 |
| `firmware/u2_openimu_emulator/` | Código-fonte e Makefile da U2 |
| `firmware/tests/` | Teste das rotinas numéricas executado no computador |
| `evidence/proteus-validation-v2.6.png` | Evidência visual do ensaio |

> O arquivo `.pdsprj` disponível é o projeto-base. A montagem final foi completada manualmente no Proteus durante o ensaio; reproduza as ligações descritas abaixo.

## Componentes

1. Duas instâncias do componente `BLUEPILL`: `U1` e `U2`.
2. Um `VGPS`.
3. Dois `VIRTUAL TERMINAL`.

Nas duas Blue Pills:

- OSC Frequency: `8MHz`;
- Clock Scale: `Off`;
- Disassemble Binary Code: `No`.

Carregue os dois arquivos HEX da versão 2.6 juntos.

## Ligações

### GPS e comunicação

| Origem | Destino | Configuração |
|---|---|---|
| `VGPS TX` | Terminal GPS `RXD` | 9600, 8N1 |
| `VGPS TX` | `U2 PA10` | USART1 RX, 9600 |
| `U2 PA2` | `U1 PA3` | pacote ACEINNA, 115200 |
| `U1 PA2` | Terminal principal `RXD` | diagnóstico, 115200, 8N1 |

Deixe `VGPS RX`, os pinos `TXD` dos terminais e todos os `RTS/CTS` sem ligação.

### Loopback dos encoders

| Saída de estímulo | Entrada de contagem |
|---|---|
| `U1 PB10` | `U1 PA0` |
| `U1 PB11` | `U1 PA1` |
| `U1 PB12` | `U1 PB6` |
| `U1 PB13` | `U1 PB7` |
| `U1 PB14` | `U1 PB8` |
| `U1 PB15` | `U1 PB9` |

## Configuração do VGPS

A evidência arquivada utiliza:

- latitude: `54.071125`;
- longitude: `-1.995949` aproximadamente;
- altitude: `100 m`;
- 10 satélites;
- aquisição a quente: 5 s.

As mensagens observadas contêm aproximadamente:

```text
$GPGGA,...,5404.2675,N,00159.7569,W,1,10,4.00,100.0,M,...
$GPRMC,...,A,5404.2675,N,00159.7569,W,...
$GPGSA,A,3,...
```

Conversão esperada da posição:

- `5404.2675,N` = `54.071125 graus`;
- `00159.7569,W` = `-1.995948 graus`;
- altitude = `100.0 m`.

## Resultado observado

O terminal principal apresentou:

```text
E2=OK CRC=OK PKT=<crescente> POS=COMPAT32 EMU=2.6 HEM=NW MODE=INS GPS=FIX
CRC_ERR=0 RX_OVF=0
```

Também foram observados valores variáveis de `RPY`, `ACC`, `L`, `R`, `ZL` e `ZR`.

A mensagem `E2=WAIT` pode aparecer entre pacotes por causa do escalonamento do modelo VSM. Ela não caracteriza falha enquanto os pacotes voltarem a aparecer, `PKT` continuar aumentando e `CRC_ERR/RX_OVF` permanecerem em zero.

## Matriz de validação

| Função | Estado | Evidência/limite |
|---|---|---|
| Geração de NMEA pelo VGPS | Validada em simulação | GGA, RMC e GSA contínuas |
| Fix e hemisférios | Validada em simulação | `GPS=FIX`, `HEM=NW` |
| UART VGPS -> U2 | Validada em simulação | 9600 baud |
| UART U2 -> U1 | Validada em simulação | 115200 baud |
| Pacote ACEINNA `e2` | Validado em simulação | preâmbulo, código, tamanho e payload |
| CRC16-CCITT | Validado em simulação | `CRC=OK`, `CRC_ERR=0` |
| Buffer de recepção | Validado no cenário simulado | `RX_OVF=0` |
| Campos IMU | Validado como transporte | dados sintéticos, sem MEMS real |
| Encoders | Validado como lógica | sinais por loopback |
| Latitude/longitude decimal | Não concluída no VSM | o NMEA está correto, mas o modelo Blue Pill corrompe a aritmética em execução |
| CAN | Não validado | modelo apresenta `CAN=NA(PROTEUS)` |
| Alimentação e integridade elétrica | Não validadas | dependem da placa física |

## Limitações

- O modelo `BLUEPILL` usado é de terceiros.
- A conversão dinâmica da latitude/longitude decimal não é confiável nesse VSM. Não use `LAT=0.000000` ou `LON=2.662615` como coordenadas aprovadas.
- U2 não representa ruído, bias, deriva térmica, calibração, EKF ou atrasos internos do OpenIMU real.
- A simulação não avalia alimentação, transientes, níveis elétricos, EMI, conectores, antena, soldagem ou temperatura.
- O CAN e o transceiver SN65HVD230 devem ser testados em bancada.

## Testes de falha

### Perda do GPS

1. Pare a simulação.
2. Desconecte `VGPS TX -> U2 PA10`.
3. Inicie novamente.
4. Confirme a transição para `GPS=NOFIX`.

### Perda da OpenIMU

1. Pare a simulação.
2. Desconecte `U2 PA2 -> U1 PA3`.
3. Inicie novamente.
4. Confirme `E2=WAIT`.
5. Reconecte e confirme o retorno de `E2=OK`.

## Referências

- [ACEINNA GPS/INS App e pacote e2](https://openimu.readthedocs.io/en/latest/apps/ins.html)
- [ACEINNA OpenIMU UART Messaging](https://openimu.readthedocs.io/en/latest/software/UARTmessaging.html)

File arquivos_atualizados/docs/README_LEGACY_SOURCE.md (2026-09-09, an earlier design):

# Módulo GPS-IMU.

## Representação 2d e 3d da placa.

<p align="left" width="100%">
  
  
</p>

## Elementos principais para a confecção da placa.

* GPS e IMU - OpenIMU300ZI.
* Esquematico do regulador de tensão fornecido pelo texas instruments no datasheet do LM1117.

<p align="center" width="100%">
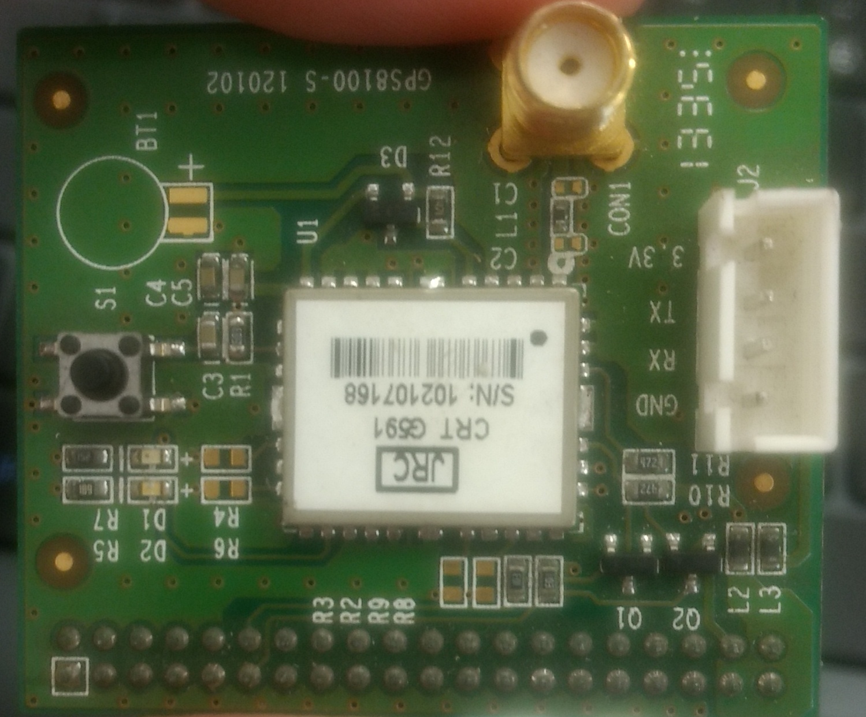
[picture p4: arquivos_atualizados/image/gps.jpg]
  
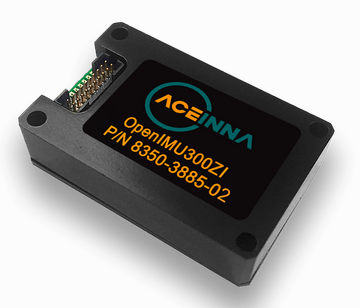
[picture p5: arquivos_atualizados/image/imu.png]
  
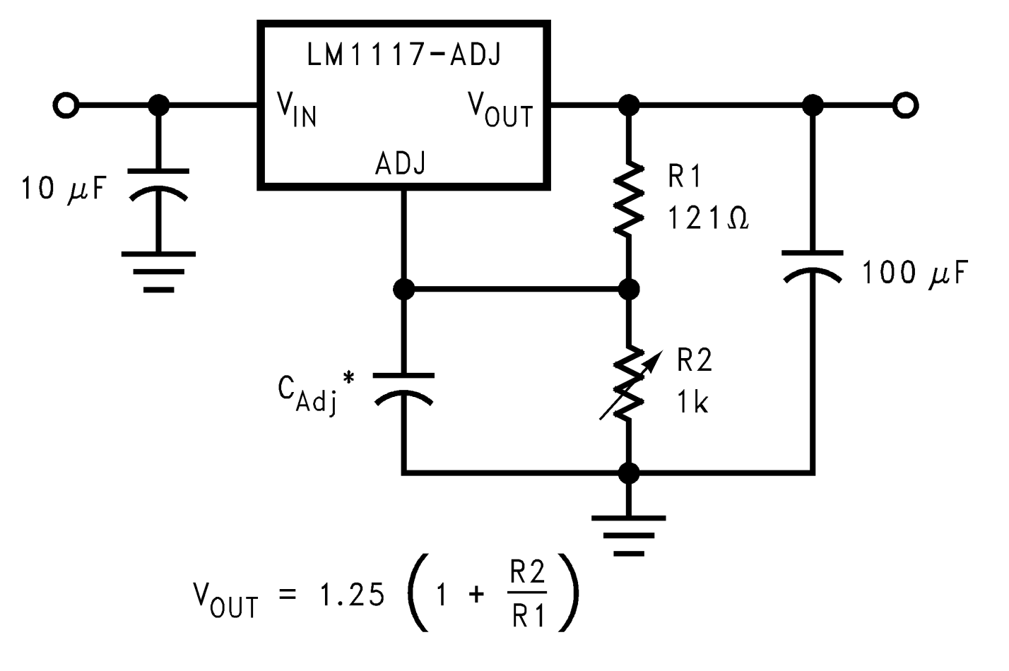
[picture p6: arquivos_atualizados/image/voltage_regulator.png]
   
</p>

## Connector e tabela de informações sobre a função de cada pino do IMU.

<p align="center" width="100%">
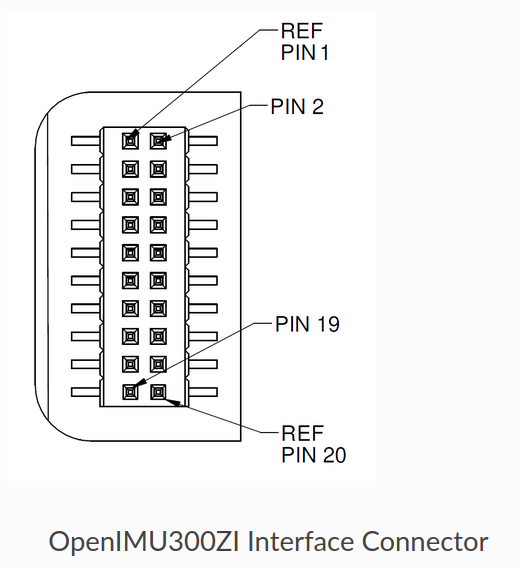
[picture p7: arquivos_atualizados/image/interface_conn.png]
    
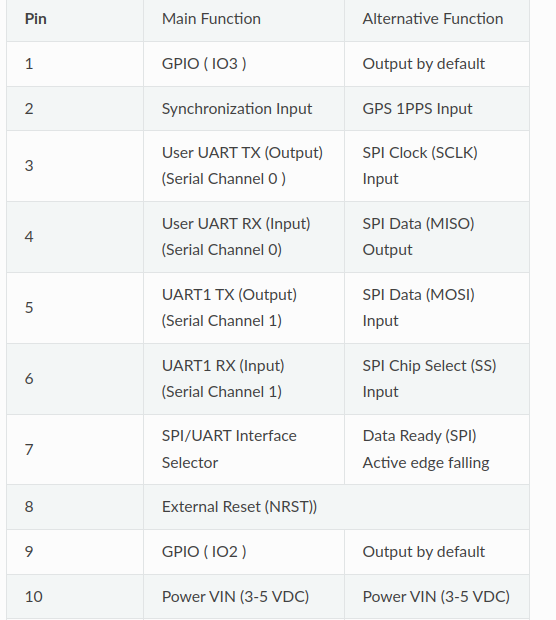
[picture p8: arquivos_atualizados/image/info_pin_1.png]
    
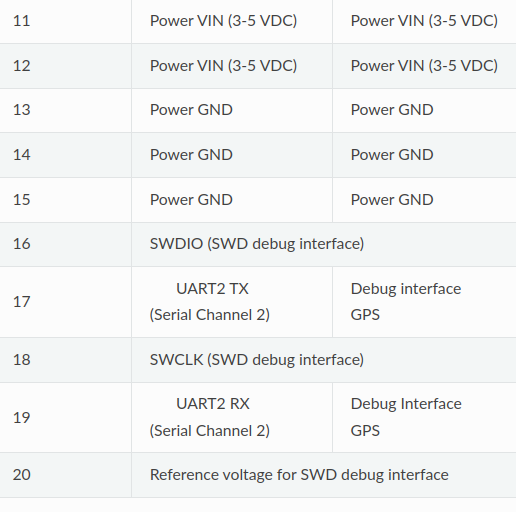
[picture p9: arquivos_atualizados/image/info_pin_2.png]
    
</p>

## Informações sobre a alimentação, conexão das portas seriais e o seletor de interface (pin_7 - comunicação UART/SPI).
<p align="center">
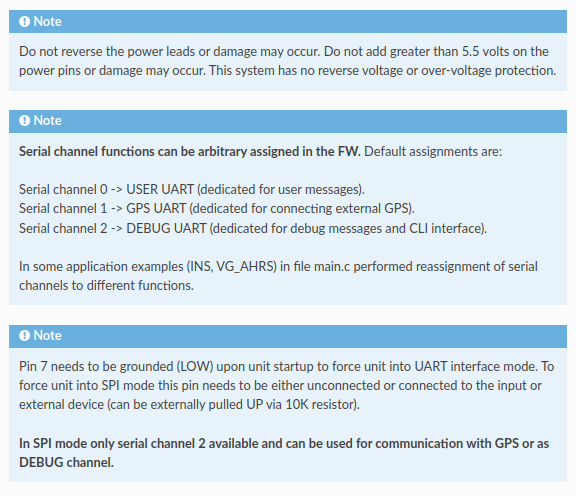
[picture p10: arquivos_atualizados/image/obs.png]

</p>

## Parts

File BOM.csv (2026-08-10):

Item | Referencias | Quantidade | Valor/Componente | Footprint | Observacao
1 | U9 | 1 | Blue Pill STM32F103 | Blue_pill:YAAJ_BluePill_SWD_2 | Confirmar variante exata do módulo e orientação
2 | U1 | 1 | TSR2-2450 | Converter_DCDC:Converter_DCDC_TRACO_TSR2-xxxx_THT | Conversor 12 V para 5 V
3 | U2 | 1 | LM1117-3.3 | LM117IMPX3.3:LM1117IMP_3.3_NOPB | Regulador 5 V para 3.3 V
4 | U3 | 1 | SN65HVD230 | Package_SO:SOIC-8_3.9x4.9mm_P1.27mm | Transceptor CAN 3.3 V
5 | U4-U6 | 3 | SRV05-4 | Package_TO_SOT_SMD:SOT-23-6_Handsoldering | Proteção dos pares de encoder; revisar máscara de solda
6 | U7-U8 | 2 | AM26LV32xD | Package_SO:SOIC-16_3.9x9.9mm_P1.27mm | Receptores diferenciais 3.3 V
7 | C1 | 1 | 22 uF | Capacitor_THT:CP_Radial_D5.0mm_P2.50mm | Filtro de +12 V
8 | C2 | 1 | 10 uF | Capacitor_THT:CP_Radial_D5.0mm_P2.50mm | Filtro de +5 V
9 | C3 | 1 | 100 uF | Capacitor_THT:CP_Radial_D5.0mm_P2.50mm | Filtro de +3.3 V
10 | C4 | 1 | 100 nF | Capacitor_THT:CP_Radial_D5.0mm_P2.50mm | Revisar valor versus footprint polarizado
11 | C5-C6 | 2 | 100 nF | Capacitor_SMD:C_0805_2012Metric_HandSolder | Desacoplamento de +3.3 V
12 | C7 | 1 | 100 nF | Capacitor_SMD:C_0805_2012Metric_HandSolder | Reset NRST para GND
13 | FB1 | 1 | Ferrite bead 0805 | Inductor_SMD:L_0805_2012Metric_HandSolder | Filtro da alimentação do GPS; definir impedância e corrente
14 | R1-R7 | 7 | 120 Ohm | Resistor_SMD:R_0805_2012Metric_HandSolder | Terminação CAN e seis pares diferenciais
15 | SW1 | 1 | FSMSM | Button_Switch_SMD:SW_SPST_FSMSM | Reset do STM32
16 | J1 | 1 | PinSocket 1x04 2.54 mm | Connector_PinSocket_2.54mm:PinSocket_1x04 | 12 V CANH CANL GND
17 | J2-J3 | 2 | PinSocket 1x08 2.54 mm | Connector_PinSocket_2.54mm:PinSocket_1x08 | Entradas dos dois encoders
18 | J4 | 1 | Conector GPS 2x20 | conn_gps_female_2x20:conn_gps_female_2x20 | Footprint customizado
19 | J5 | 1 | Conector IMU 2x10 | imu_connector_female_2x10:imu_connector_female_2x10 | Footprint customizado
20 | JTAG_IMU1 | 1 | PinSocket 1x04 2.54 mm | Connector_PinSocket_2.54mm:PinSocket_1x04 | Pino 4 sem conexão; revisar GND

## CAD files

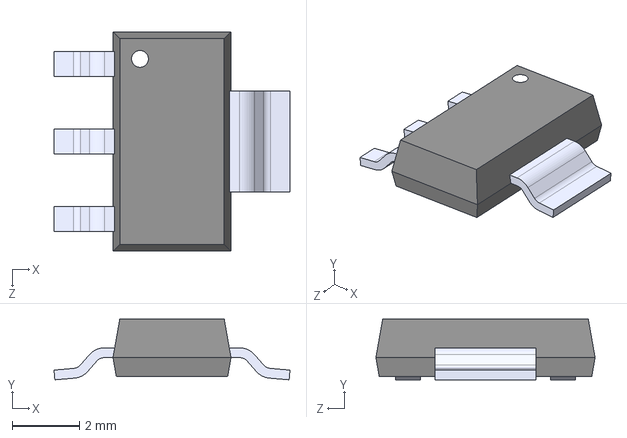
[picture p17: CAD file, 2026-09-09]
arquivos_atualizados/Kicad-STM32-master/LM1117IMPX-3.3_NOPB(1)/LM1117IMPX-3.3_NOPB.step
7.00 x 1.80 x 6.50 mm

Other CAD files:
arquivos_atualizados/Kicad-STM32-master/LM1117IMPX-5.0/LM1117IMPX-5.0.step

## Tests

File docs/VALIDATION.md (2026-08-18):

# Validação do projeto

## Resumo

| Área | Estado |
|---|---|
| GPS/NMEA e UART no Proteus | Validado funcionalmente |
| Pacote ACEINNA `e2` e CRC | Validado funcionalmente |
| Campos sintéticos de IMU | Transporte validado |
| Lógica simulada dos encoders | Validada |
| Conversão decimal da posição no VSM | Não concluída |
| CAN | Não validado |
| Alimentação e integridade elétrica | Não validadas |
| Sensores e encoders reais | Não validados |
| DRC para fabricação | Reprovado/pedente de correções |

O procedimento e as evidências do Proteus estão em [`simulation/proteus`](../simulation/proteus/README.md).

## DRC fornecido

O relatório `DRC.txt`, de 30/07/2026, registra:

| Categoria | Quantidade |
|---|---:|
| Pontes de máscara de solda | 12 |
| Violações de clearance | 5 |
| Texto espelhado | 1 |
| Serigrafia sobre cobre | 2 |
| Total | 20 |

O relatório também registra zero pads desconectados, mas isso não elimina as violações restantes.

## Antes da fabricação

1. Corrigir as violações de máscara e clearance.
2. Corrigir texto e serigrafia.
3. Conferir J2/J3 e todos os footprints customizados.
4. Corrigir os caminhos não portáveis das bibliotecas.
5. Executar ERC e DRC novamente.
6. Gerar Gerbers somente após revisão com zero erro crítico.

## Depois da placa montada

### Alimentação

1. Ensaiar inicialmente sem Blue Pill, GPS, IMU e encoders.
2. Verificar resistência entre as linhas de alimentação e GND.
3. Alimentar com fonte limitada em corrente.
4. Medir 5 V e 3,3 V, ripple, corrente e temperatura.
5. Instalar os módulos progressivamente.

### Comunicação e sensores

- validar UART com os módulos físicos;
- confirmar a conversão NMEA para latitude/longitude;
- testar fix, perda e recuperação do GPS;
- medir bias, ruído, deriva, orientação e calibração da IMU;
- testar A/B/Z dos dois encoders em ambos os sentidos;
- testar CAN, bitrate, IDs, terminação, erros e bus-off;
- executar teste prolongado e falhas por desconexão.

## Critério de comunicação para a reunião

A conclusão correta é: a lógica digital e o protocolo foram validados em simulação, enquanto a liberação elétrica, mecânica e de fabricação depende da placa física e da correção do DRC.

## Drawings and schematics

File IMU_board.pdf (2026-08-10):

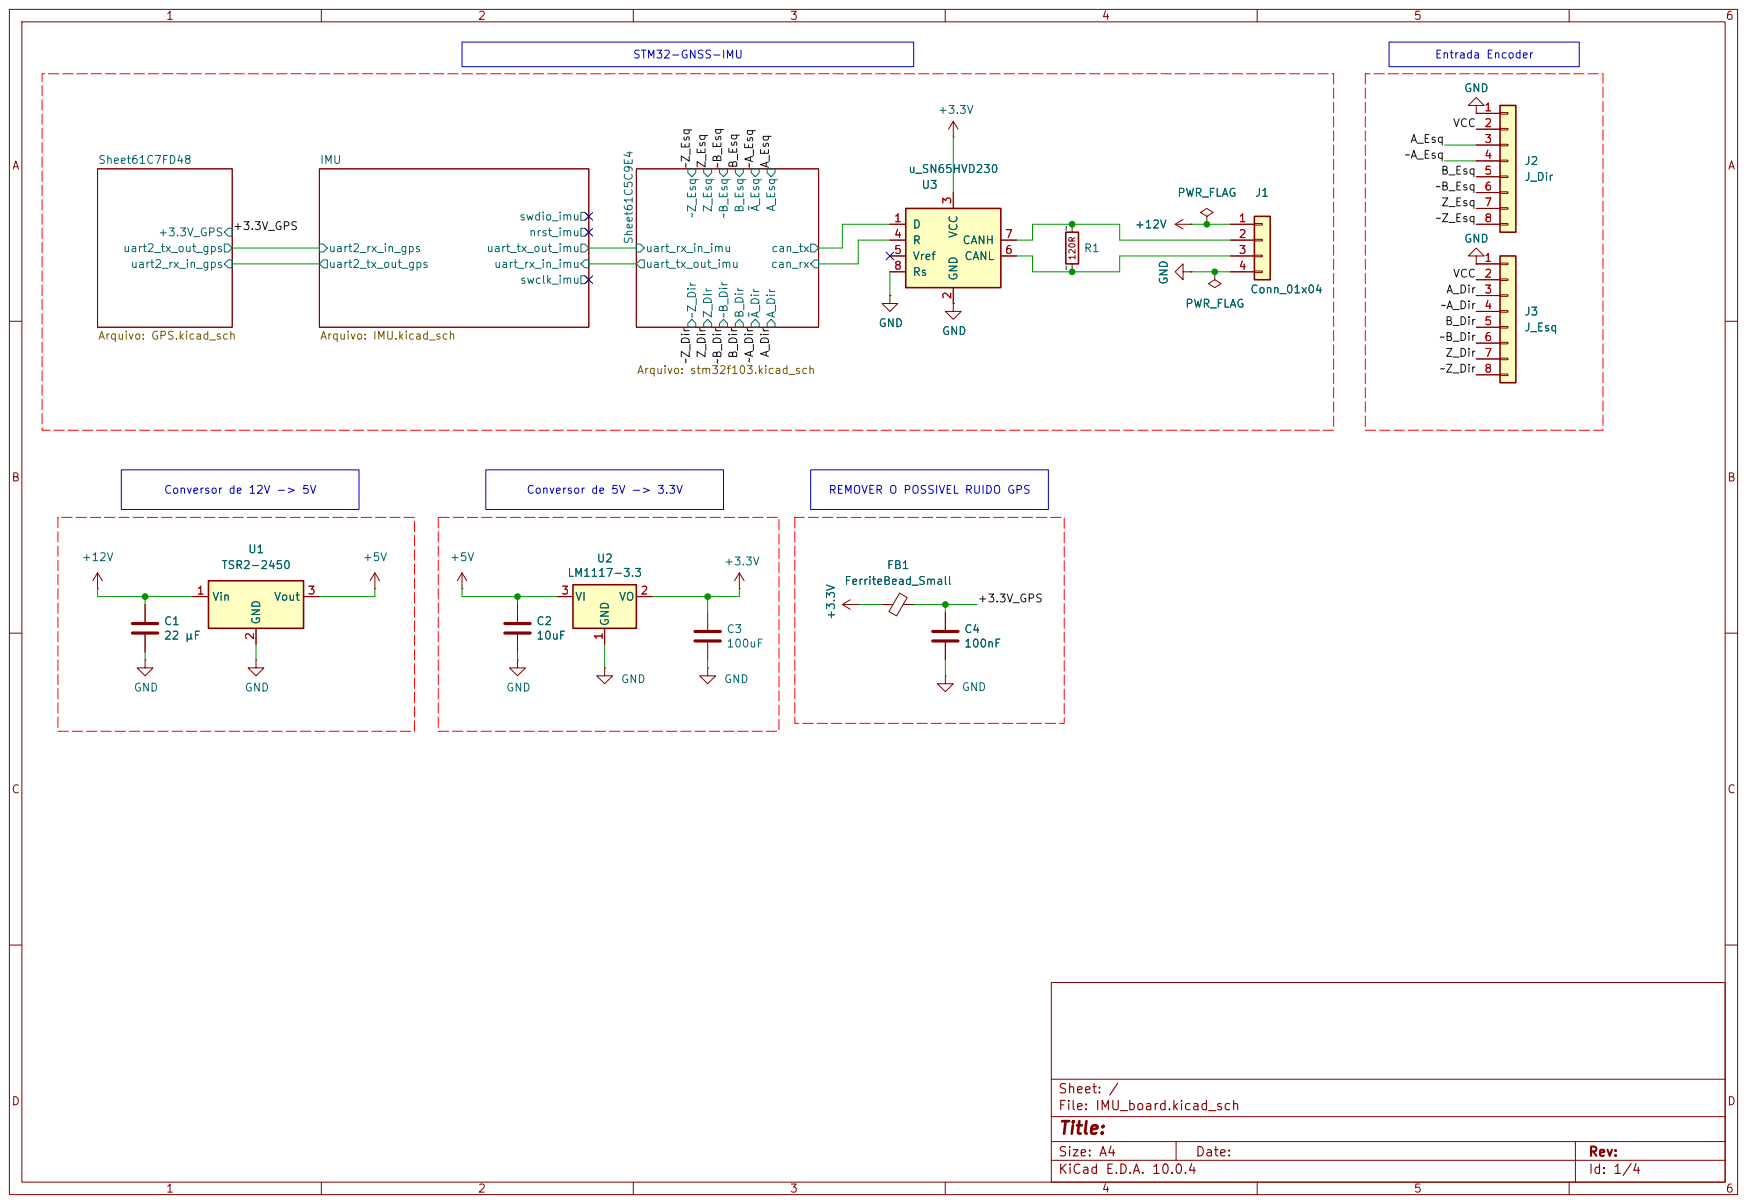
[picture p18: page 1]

Size: A4 | Rev:
KiCad E.D.A. 10.0.4 | Id: 1/4

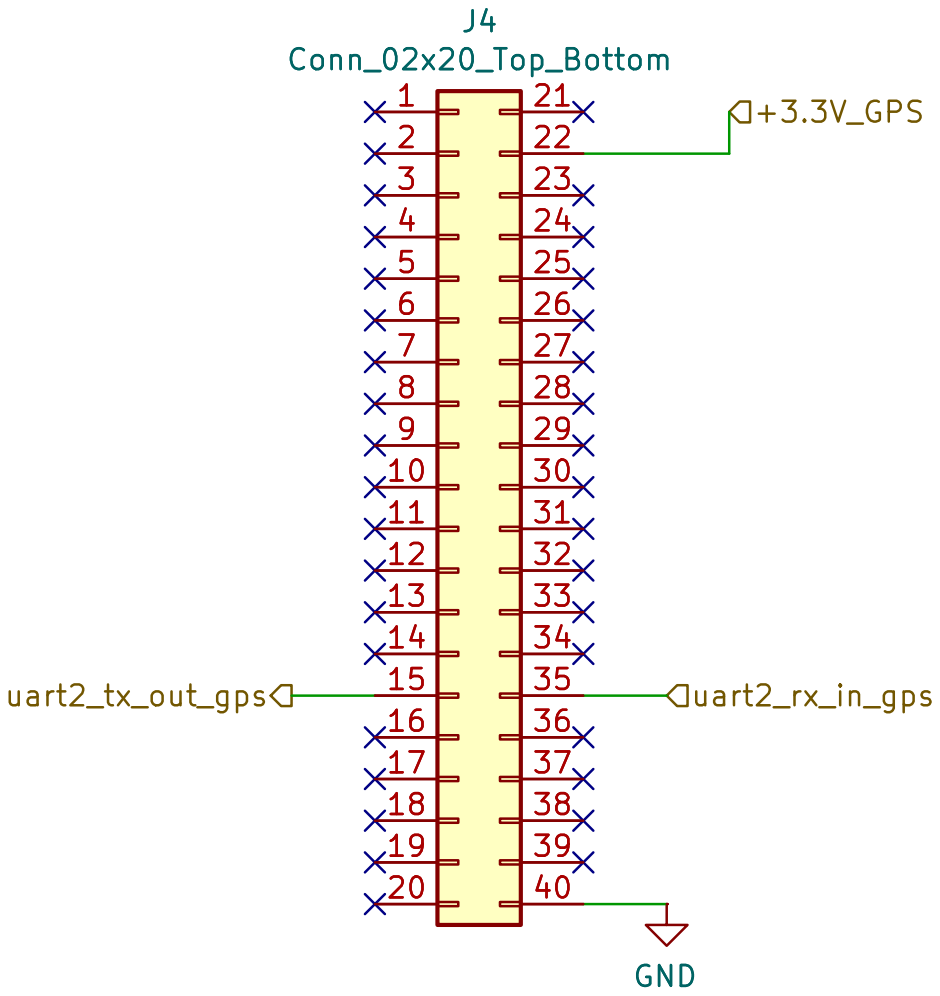
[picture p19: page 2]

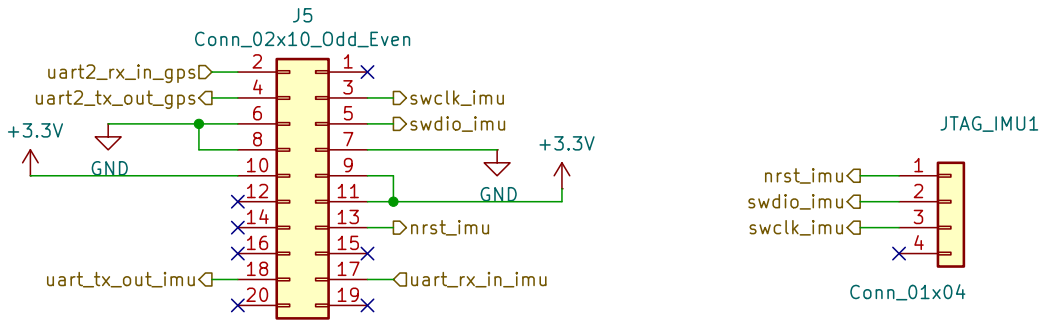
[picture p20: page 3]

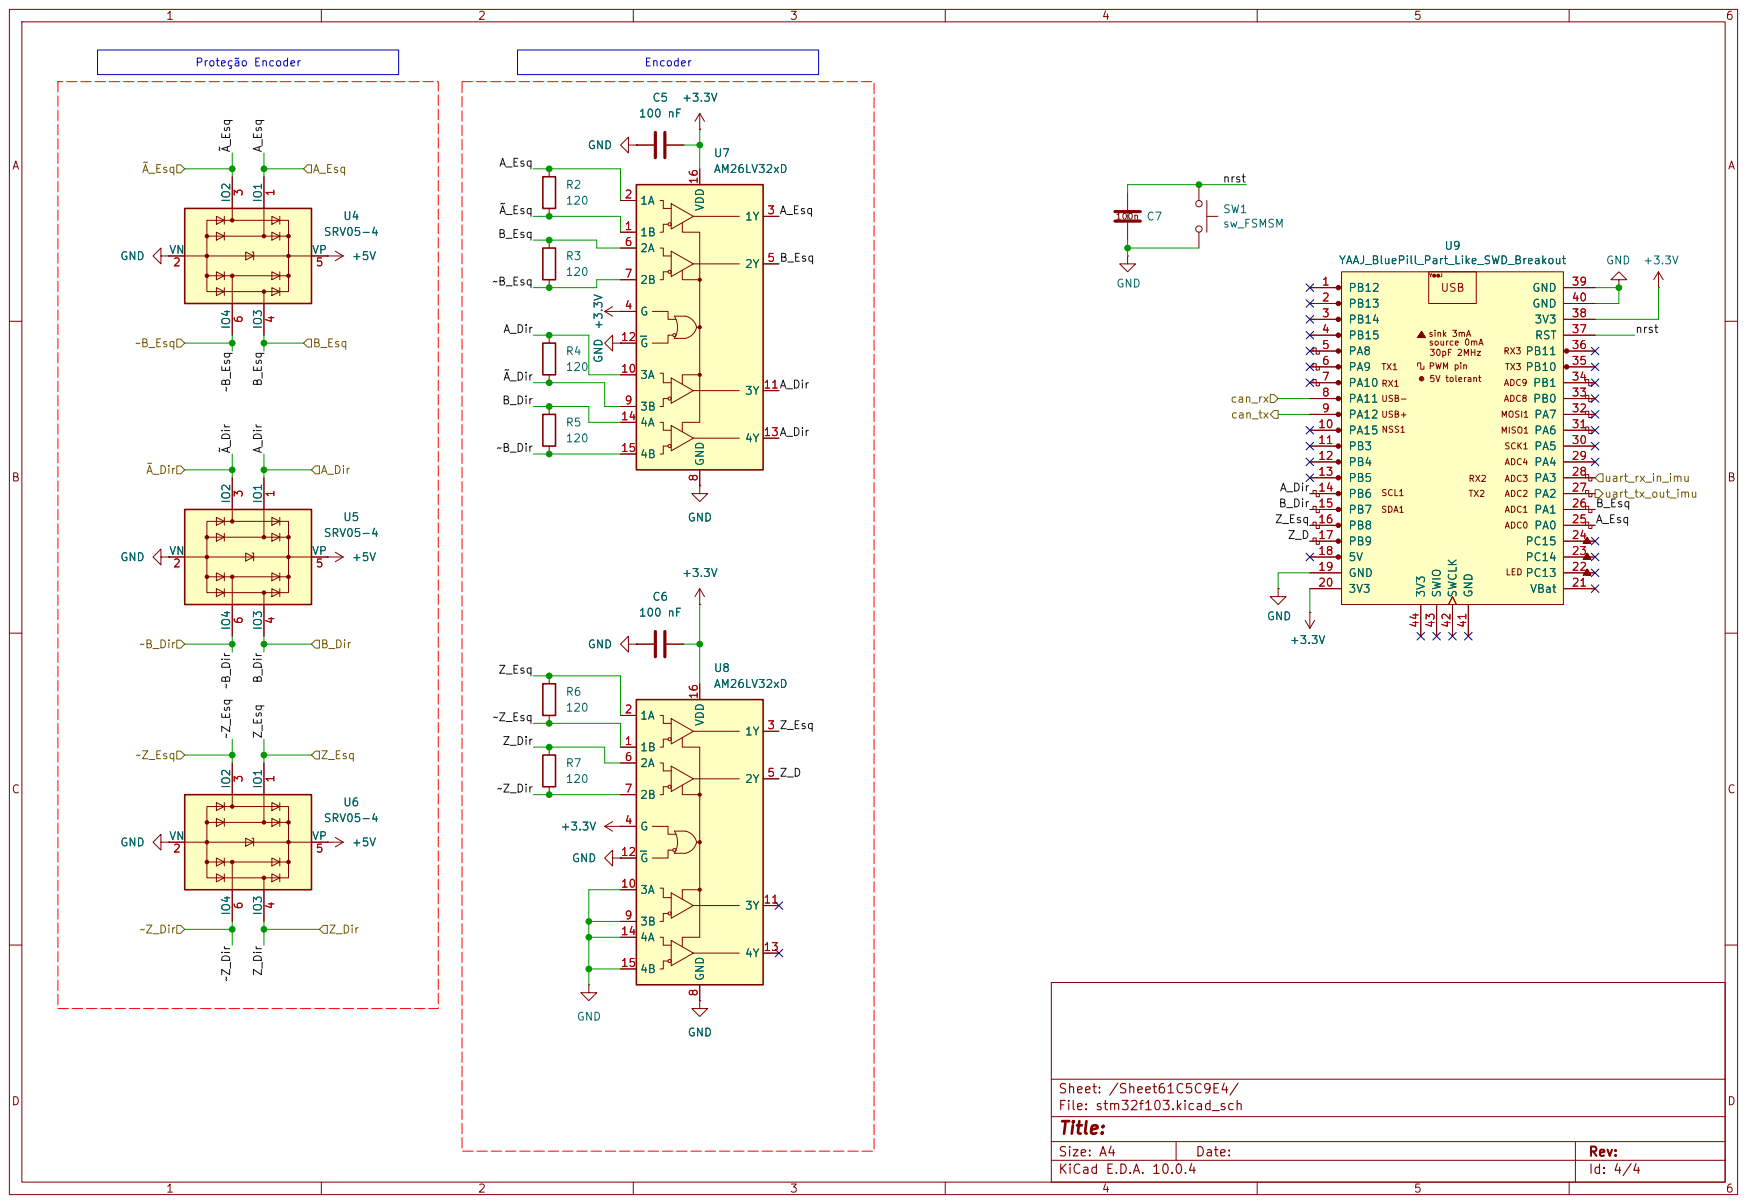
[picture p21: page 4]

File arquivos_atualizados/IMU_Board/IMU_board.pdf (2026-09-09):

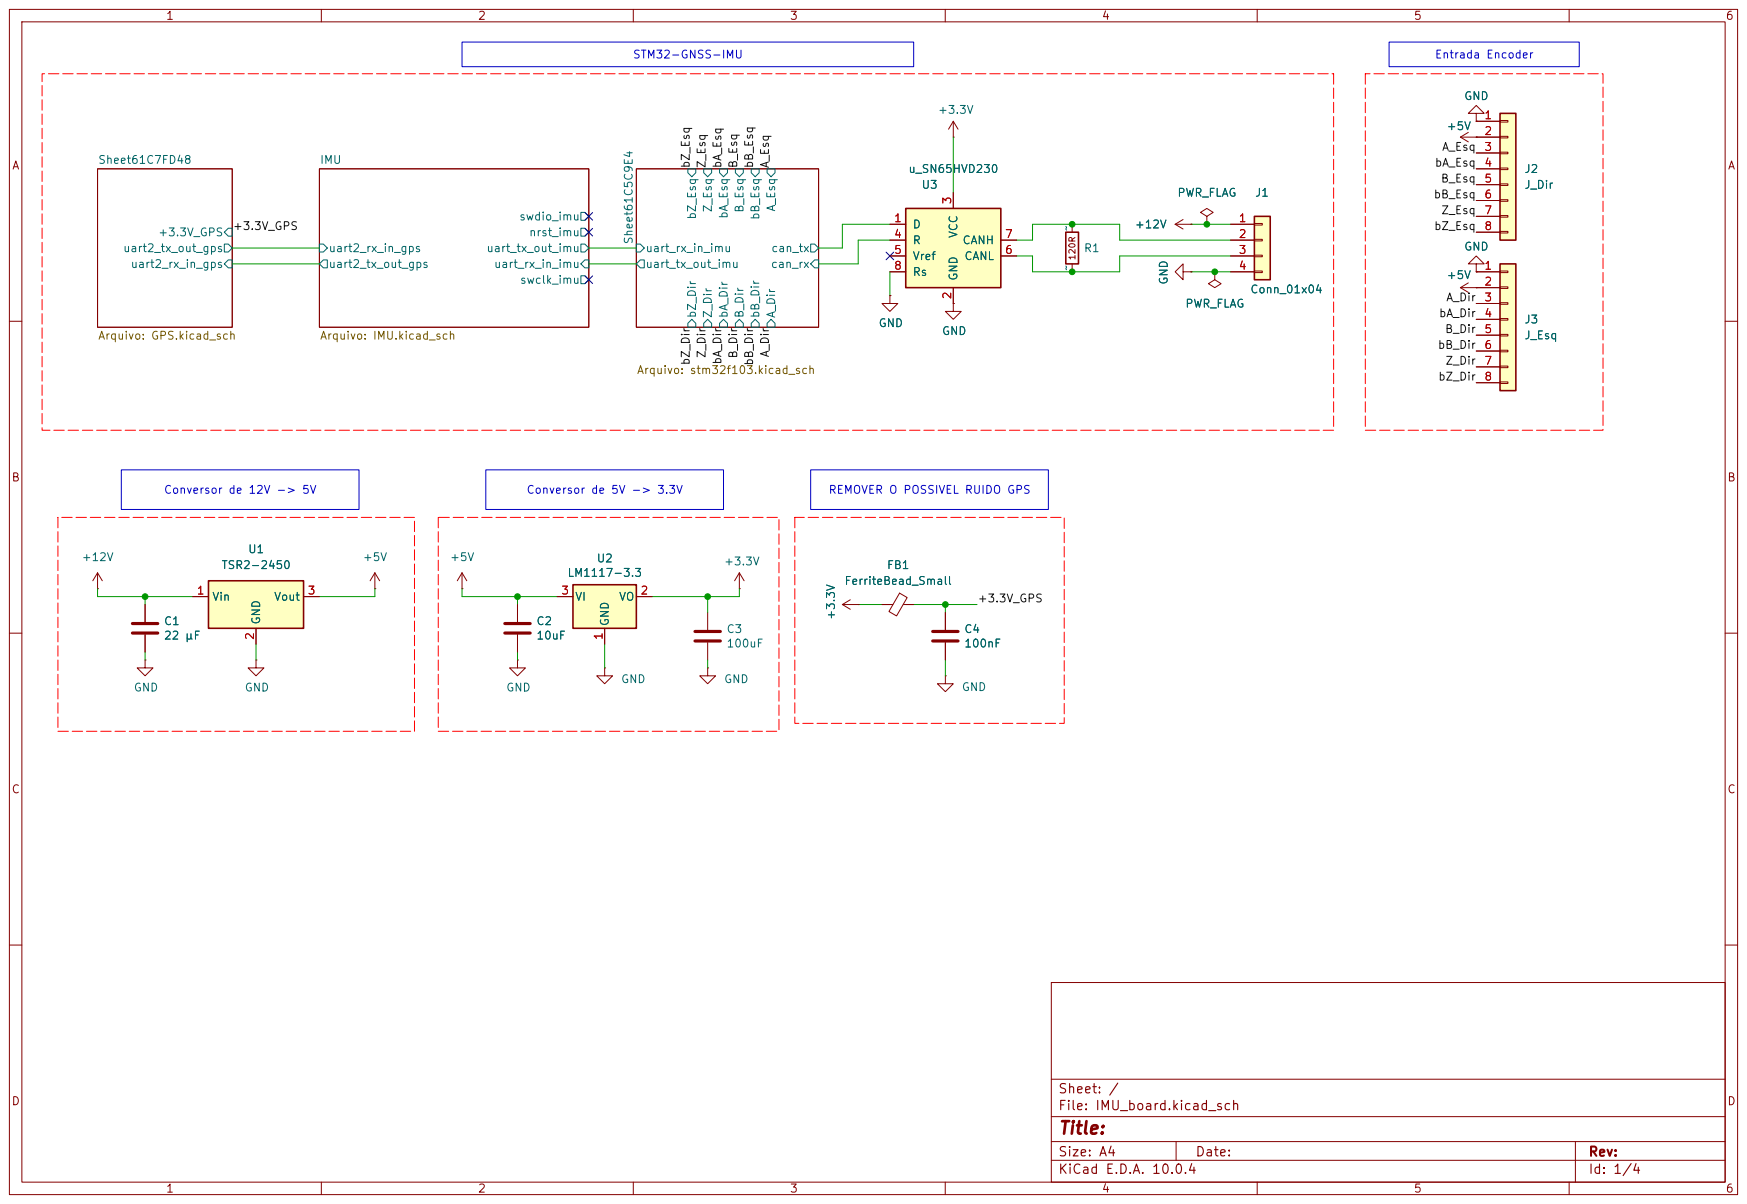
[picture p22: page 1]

Size: A4 | Rev:
KiCad E.D.A. 10.0.4 | Id: 1/4

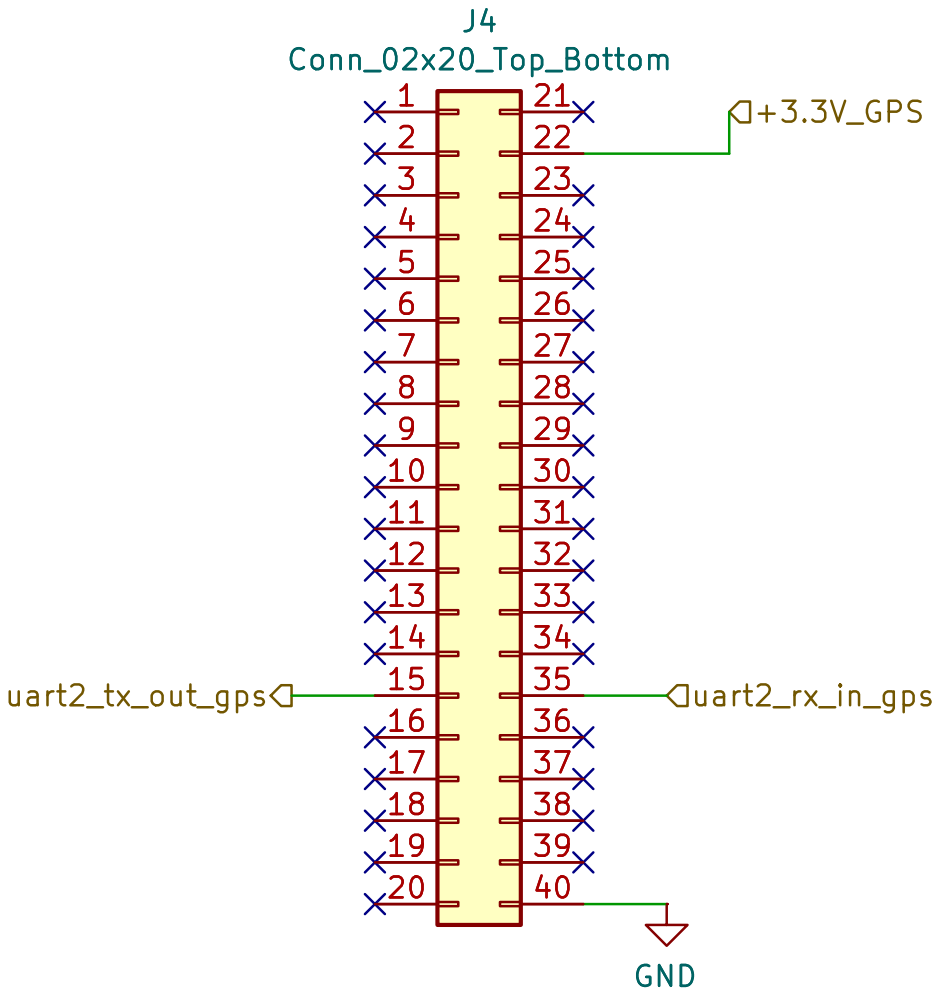
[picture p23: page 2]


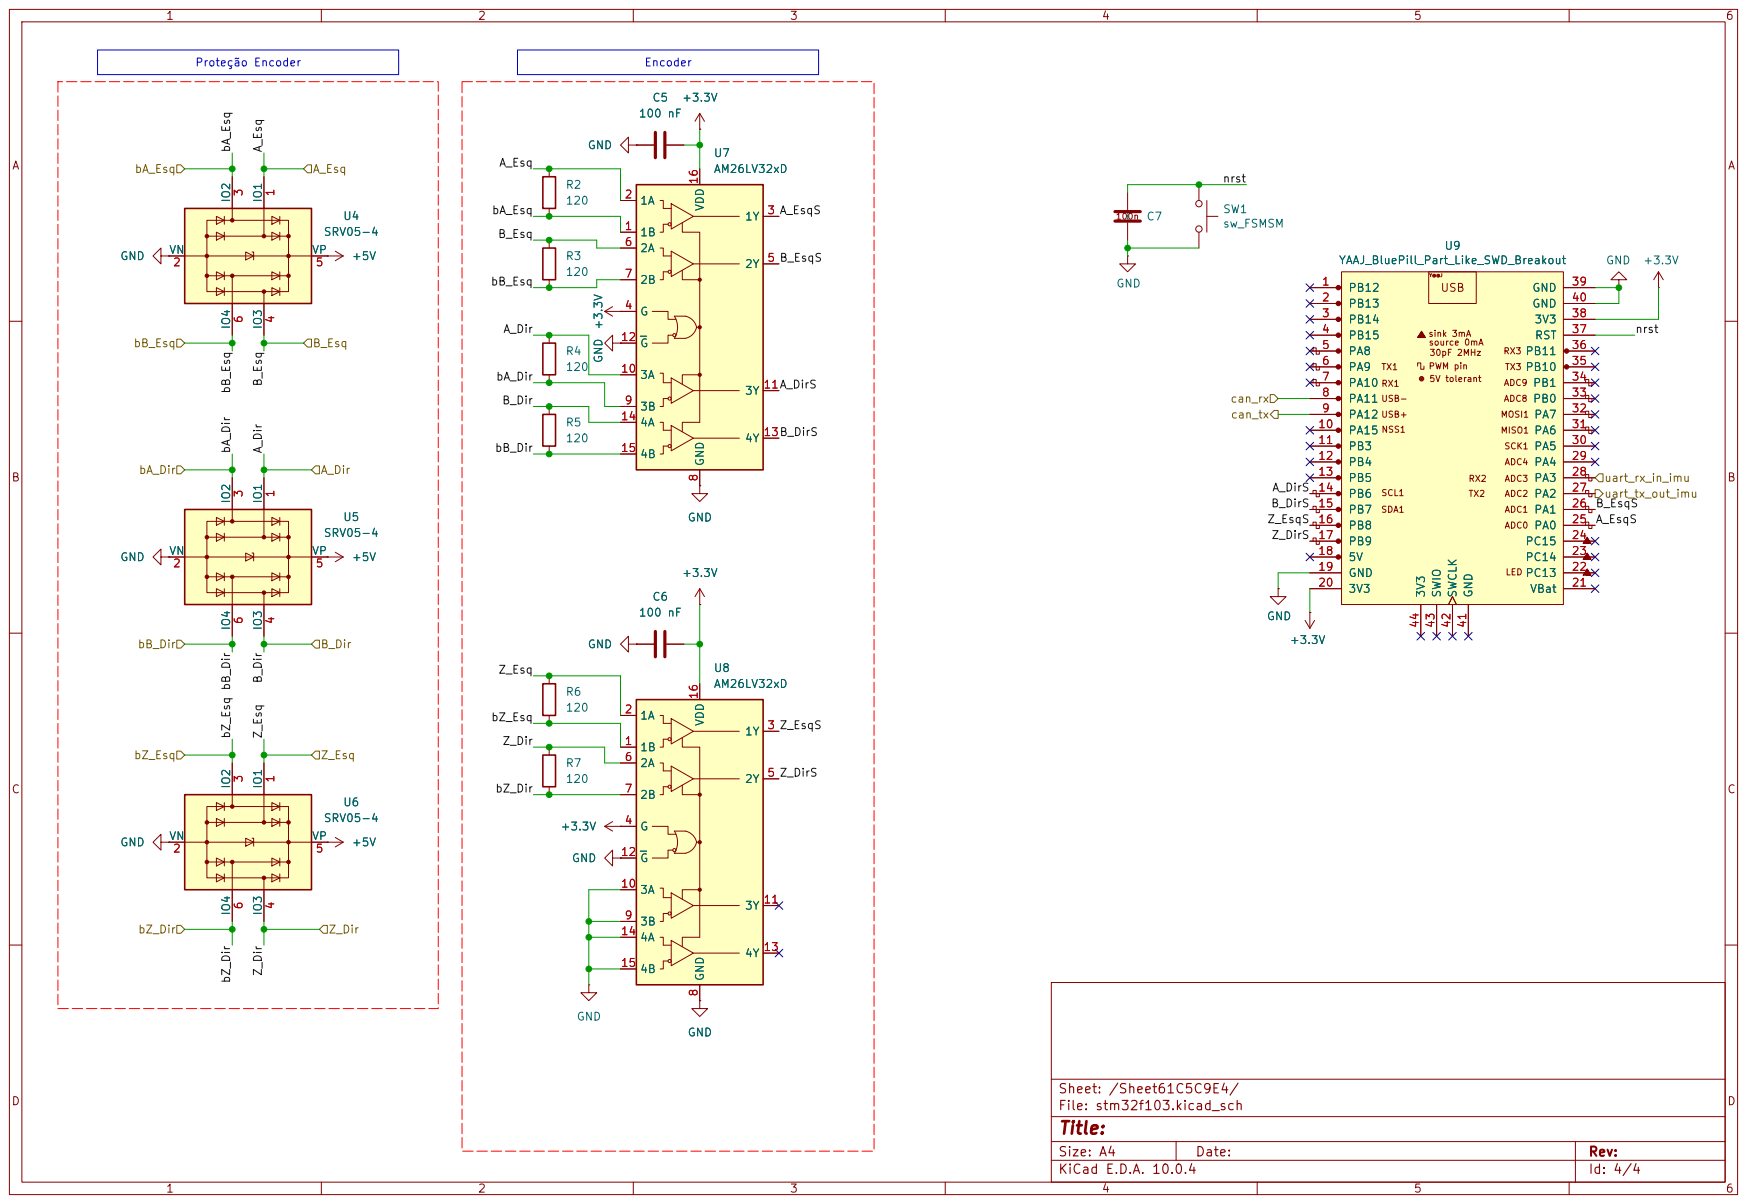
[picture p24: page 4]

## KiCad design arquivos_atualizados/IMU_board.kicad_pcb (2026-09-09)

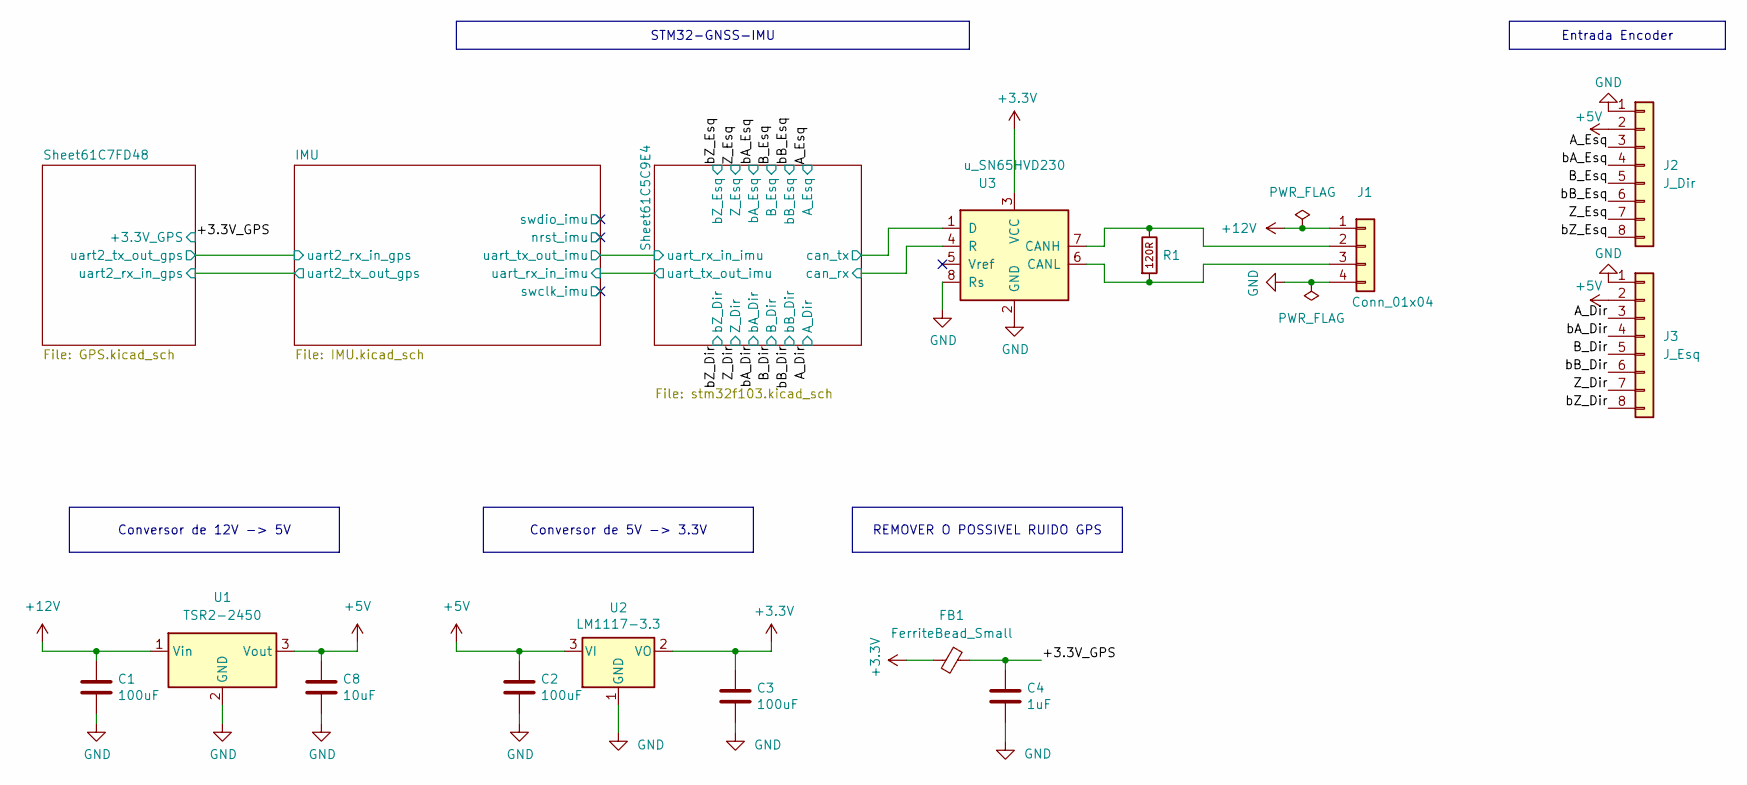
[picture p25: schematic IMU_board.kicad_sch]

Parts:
C1, C2, C3: 100uF; CP_Radial_D5.0mm_P2.50mm
C4: 1uF; C_0805_2012Metric
C8: 10uF; CP_Radial_D5.0mm_P2.50mm
FB1: FerriteBead_Small; L_0805_2012Metric_Pad1.05x1.20mm_HandSolder
J1: Conn_01x04; Molex_Micro-Fit_3.0_Molex_Micro-Fit_3.0_Header_Vertical_1x0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
J2: J_Dir; Molex_Micro-Fit_3.0_Molex_Micro-Fit_3.0_Header_Vertical_1x0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
J3: J_Esq; Molex_Micro-Fit_3.0_Molex_Micro-Fit_3.0_Header_Vertical_1x0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
R1: r_120; R_0805_2012Metric_Pad1.20x1.40mm_HandSolder; MPN ERJ-P06F1200V
U1: TSR2-2450; Converter_DCDC_TRACO_TSR2-xxxx_THT
U2: LM1117-3.3; LM1117IMP_3.3_NOPB
U3: u_SN65HVD230; SOIC-8_3.9x4.9mm_P1.27mm; MPN SN65HVD230MDREP

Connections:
+3.3V: C3.1, FB1.2, U2.2 (VO), U3.3 (VCC); also elsewhere on the board
+5V: C2.1, C8.1, J2.2, J3.2, U1.3 (Vout), U2.3 (VI); also elsewhere on the board
+12V: C1.1, J1.1, U1.1 (Vin)
/+3.3V_GPS: C4.1, FB1.1; also elsewhere on the board
/A_Dir: J3.3; also elsewhere on the board
/A_Esq: J2.3; also elsewhere on the board
/B_Dir: J3.5; also elsewhere on the board
/B_Esq: J2.5; also elsewhere on the board
/Sheet61C5C9E4/can_rx: U3.4 (R); also elsewhere on the board
/Sheet61C5C9E4/can_tx: U3.1 (D); also elsewhere on the board
/Z_Dir: J3.7; also elsewhere on the board
/Z_Esq: J2.7; also elsewhere on the board
/bA_Dir: J3.4; also elsewhere on the board
/bA_Esq: J2.4; also elsewhere on the board
/bB_Dir: J3.6; also elsewhere on the board
/bB_Esq: J2.6; also elsewhere on the board
/bZ_Dir: J3.8; also elsewhere on the board
/bZ_Esq: J2.8; also elsewhere on the board
GND: C1.2, C2.2, C3.2, C4.2, C8.2, J1.4, J2.1, J3.1, U1.2 (GND), U2.1 (GND), U3.2 (GND), U3.8 (Rs); also elsewhere on the board
unnamed: J1.2, R1.1, U3.7 (CANH)
unnamed: J1.3, R1.2, U3.6 (CANL)

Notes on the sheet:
Conversor de 12V -> 5V
REMOVER O POSSIVEL RUIDO GPS
Entrada Encoder
Conversor de 5V -> 3.3V
STM32-GNSS-IMU

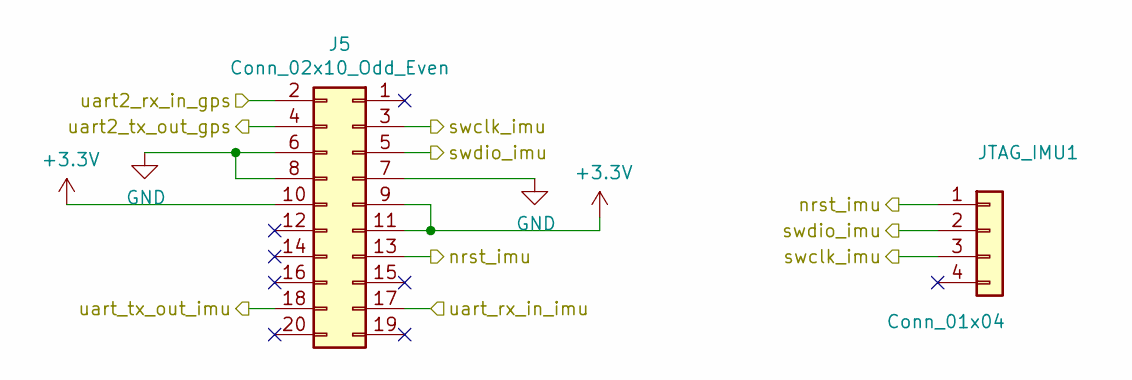
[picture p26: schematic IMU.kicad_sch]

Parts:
J5: Conn_02x10_Odd_Even; imu_connector_female_2x10
JTAG_IMU1: Conn_01x04; Molex_Micro-Fit_3.0_Molex_Micro-Fit_3.0_Header_Vertical_1x0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

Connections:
+3.3V: J5.9, J5.10, J5.11; also elsewhere on the board
/IMU/nrst_imu: J5.13, JTAG_IMU1.1
/IMU/swclk_imu: J5.3, JTAG_IMU1.3
/IMU/swdio_imu: J5.5, JTAG_IMU1.2
/IMU/uart2_rx_in_gps: J5.2; also elsewhere on the board
/IMU/uart2_tx_out_gps: J5.4; also elsewhere on the board
/IMU/uart_rx_in_imu: J5.17; also elsewhere on the board
/IMU/uart_tx_out_imu: J5.18; also elsewhere on the board
GND: J5.6, J5.7, J5.8; also elsewhere on the board

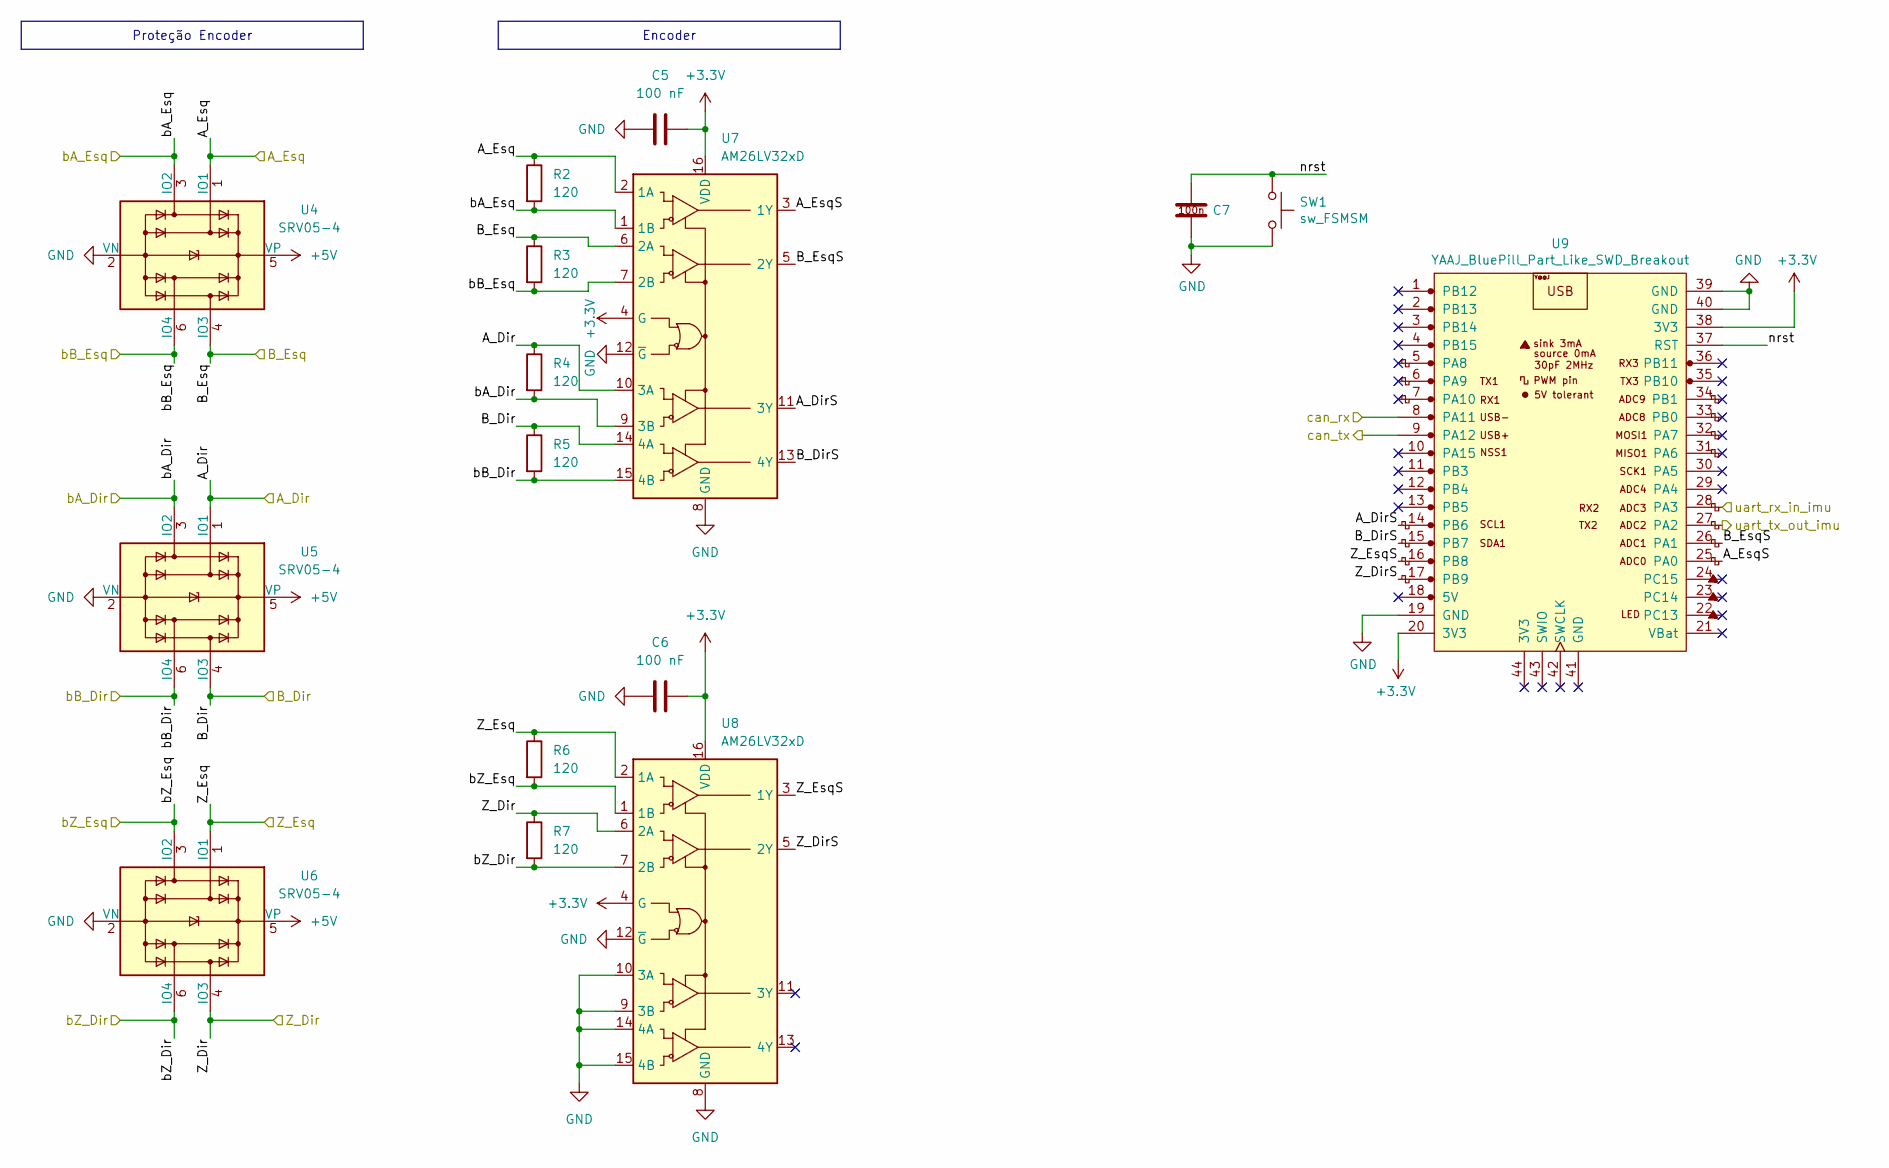
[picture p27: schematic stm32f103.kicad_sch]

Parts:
C5, C6: 100 nF; C_0805_2012Metric_Pad1.18x1.45mm_HandSolder
C7: c_100n; C_0805_2012Metric_Pad1.18x1.45mm_HandSolder; MPN 08055C104KAT2A
R2, R3, R4, R5, R6, R7: 120; R_0805_2012Metric_Pad1.20x1.40mm_HandSolder
SW1: sw_FSMSM; SW_SPST_FSMSM; MPN FSMSM
U4, U5, U6: SRV05-4; SOT-23-6_Handsoldering
U7, U8: AM26LV32xD; SOIC-16_3.9x9.9mm_P1.27mm
U9: YAAJ_BluePill_Part_Like_SWD_Breakout; YAAJ_BluePill_SWD_2

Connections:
+3.3V: C5.2, C6.2, U7.4 (G), U7.16 (VDD), U8.4 (G), U8.16 (VDD), U9.20 (3V3), U9.38 (3V3); also elsewhere on the board
+5V: U4.5 (VP), U5.5 (VP), U6.5 (VP); also elsewhere on the board
/A_Dir: R4.1, U5.1 (IO1), U7.10 (3A); also elsewhere on the board
/A_Esq: R2.1, U4.1 (IO1), U7.2 (1A); also elsewhere on the board
/B_Dir: R5.1, U5.4 (IO3), U7.14 (4A); also elsewhere on the board
/B_Esq: R3.1, U4.4 (IO3), U7.6 (2A); also elsewhere on the board
/IMU/uart_rx_in_imu: U9.27 (PA2); also elsewhere on the board
/IMU/uart_tx_out_imu: U9.28 (PA3); also elsewhere on the board
/Sheet61C5C9E4/A_DirS: U7.11 (3Y), U9.14 (PB6)
/Sheet61C5C9E4/A_EsqS: U7.3 (1Y), U9.25 (PA0)
/Sheet61C5C9E4/B_DirS: U7.13 (4Y), U9.15 (PB7)
/Sheet61C5C9E4/B_EsqS: U7.5 (2Y), U9.26 (PA1)
/Sheet61C5C9E4/Z_DirS: U8.5 (2Y), U9.17 (PB9)
/Sheet61C5C9E4/Z_EsqS: U8.3 (1Y), U9.16 (PB8)
/Sheet61C5C9E4/can_rx: U9.8 (PA11); also elsewhere on the board
/Sheet61C5C9E4/can_tx: U9.9 (PA12); also elsewhere on the board
/Sheet61C5C9E4/nrst: C7.1, SW1.1, U9.37 (RST)
/Z_Dir: R7.1, U6.4 (IO3), U8.6 (2A); also elsewhere on the board
/Z_Esq: R6.1, U6.1 (IO1), U8.2 (1A); also elsewhere on the board
/bA_Dir: R4.2, U5.3 (IO2), U7.9 (3B); also elsewhere on the board
/bA_Esq: R2.2, U4.3 (IO2), U7.1 (1B); also elsewhere on the board
/bB_Dir: R5.2, U5.6 (IO4), U7.15 (4B); also elsewhere on the board
/bB_Esq: R3.2, U4.6 (IO4), U7.7 (2B); also elsewhere on the board
/bZ_Dir: R7.2, U6.6 (IO4), U8.7 (2B); also elsewhere on the board
/bZ_Esq: R6.2, U6.3 (IO2), U8.1 (1B); also elsewhere on the board
GND: C5.1, C6.1, C7.2, SW1.2, U4.2 (VN), U5.2 (VN), U6.2 (VN), U7.8 (GND), U7.12 (~G), U8.8 (GND), U8.9 (3B), U8.10 (3A), U8.12 (~G), U8.14 (4A), U8.15 (4B), U9.19 (GND), U9.39 (GND), U9.40 (GND); also elsewhere on the board

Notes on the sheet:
Encoder
Proteção Encoder

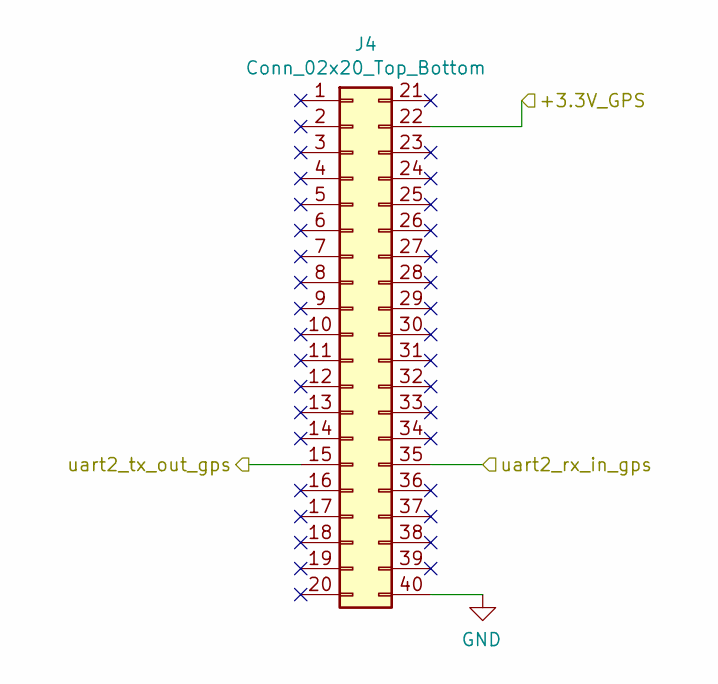
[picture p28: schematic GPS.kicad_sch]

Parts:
J4: Conn_02x20_Top_Bottom; conn_gps_female_2x20

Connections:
/+3.3V_GPS: J4.22; also elsewhere on the board
/IMU/uart2_rx_in_gps: J4.15; also elsewhere on the board
/IMU/uart2_tx_out_gps: J4.35; also elsewhere on the board
GND: J4.40; also elsewhere on the board

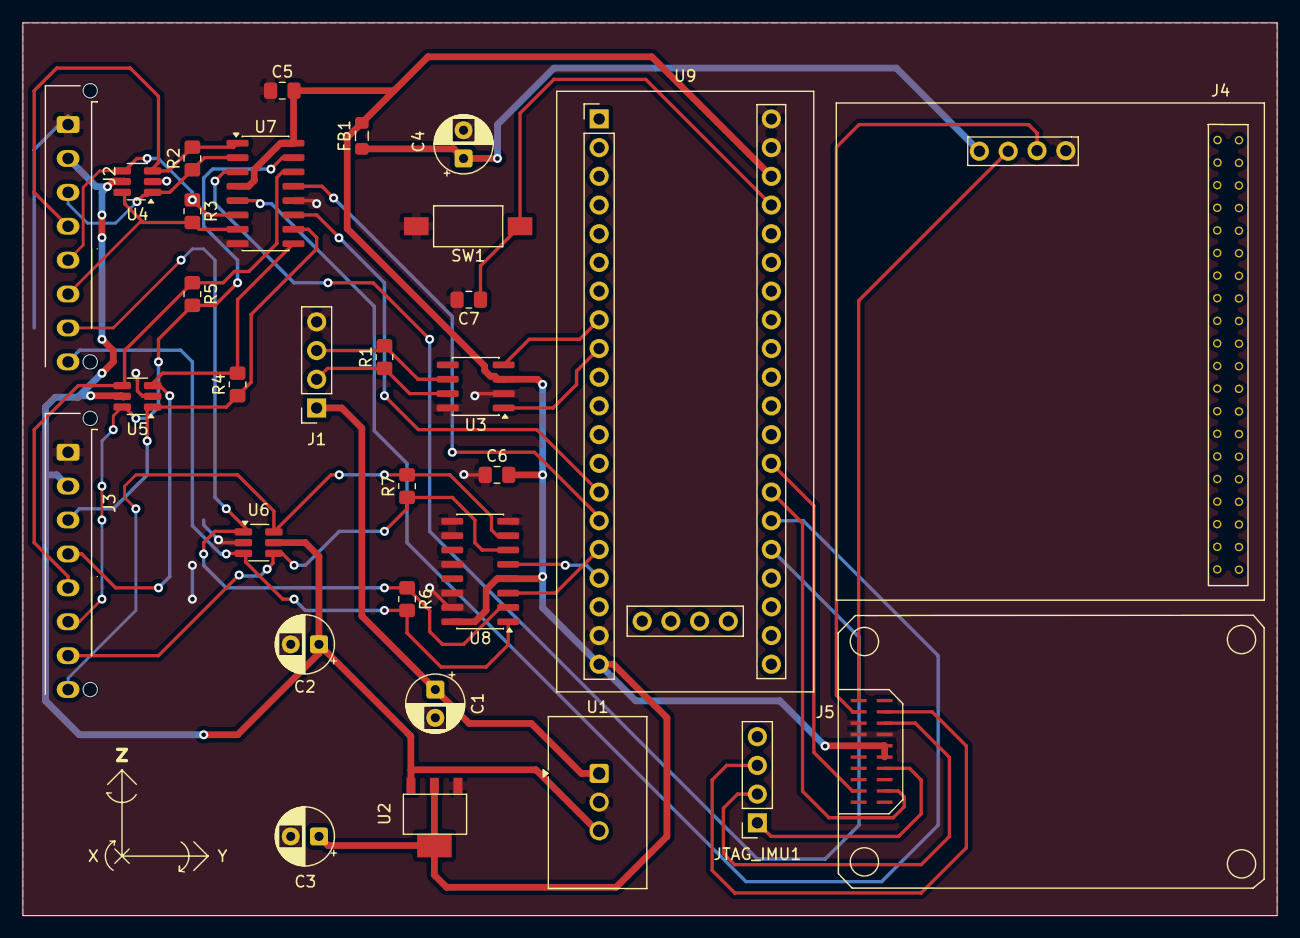
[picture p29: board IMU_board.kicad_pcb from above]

Board: 4 copper layers, 111.0 x 79.0 mm, 31 parts (0 on the bottom side), 35 nets.

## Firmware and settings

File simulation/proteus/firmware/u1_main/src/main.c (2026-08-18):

#include <stdint.h>
#include <stdbool.h>

/*
 * Receptor principal U1 para validacao integrada no Proteus.
 *
 * - Mantem os dois encoders A/B/Z da versao 1.3.
 * - Recebe o pacote oficial ACEINNA GPS/INS "e2" em PA3/USART2_RX.
 * - Mostra diagnostico em PA2/USART2_TX, 115200 baud.
 * - Valida preambulo, codigo, tamanho e CRC16-CCITT.
 *
 * O CAN continua desabilitado porque o modelo BLUEPILL VSM de terceiros
 * encerra/trava a simulacao ao acessar os registradores CAN.
 */

#define REG32(addr) (*(volatile uint32_t *)(addr))

#define RCC_BASE        0x40021000u
#define RCC_APB2ENR     REG32(RCC_BASE + 0x18u)
#define RCC_APB1ENR     REG32(RCC_BASE + 0x1Cu)

#define AFIO_BASE       0x40010000u
#define AFIO_EXTICR3    REG32(AFIO_BASE + 0x10u)

#define EXTI_BASE       0x40010400u
#define EXTI_IMR        REG32(EXTI_BASE + 0x00u)
#define EXTI_RTSR       REG32(EXTI_BASE + 0x08u)
#define EXTI_PR         REG32(EXTI_BASE + 0x14u)

#define GPIOA_BASE      0x40010800u
#define GPIOB_BASE      0x40010C00u
#define GPIO_IDR(base)  REG32((base) + 0x08u)
#define GPIO_ODR(base)  REG32((base) + 0x0Cu)

#define USART2_BASE     0x40004400u
#define USART2_SR       REG32(USART2_BASE + 0x00u)
#define USART2_DR       REG32(USART2_BASE + 0x04u)
#define USART2_BRR      REG32(USART2_BASE + 0x08u)
#define USART2_CR1      REG32(USART2_BASE + 0x0Cu)

#define SYST_CSR        REG32(0xE000E010u)
#define SYST_RVR        REG32(0xE000E014u)
#define SYST_CVR        REG32(0xE000E018u)
#define NVIC_ISER0      REG32(0xE000E100u)
#define NVIC_ISER1      REG32(0xE000E104u)

#define RX_BUFFER_SIZE  256u

typedef struct {
    uint32_t timer_ms;
    float roll;
    float pitch;
    float yaw;
    float accel_x;
    float accel_y;
    float accel_z;
    float gyro_x;
    float gyro_y;
    float gyro_z;
    float vel_n;
    float vel_e;
    float vel_d;
    int32_t latitude_microdegrees;
    int32_t longitude_microdegrees;
    int32_t altitude_decimeters;
    uint8_t mode;
    uint8_t linear_accel_switch;
    uint8_t turn_switch;
} e2_data_t;

static volatile uint32_t g_ms;
static volatile uint32_t g_z_left;
static volatile uint32_t g_z_right;
static int32_t g_encoder_left;
static int32_t g_encoder_right;
static uint8_t g_prev_left;
static uint8_t g_prev_right;
static bool g_encoder_sample_ready;

static volatile uint8_t g_rx_buffer[RX_BUFFER_SIZE];
static volatile uint16_t g_rx_head;
static volatile uint16_t g_rx_tail;
static volatile uint32_t g_rx_overflow;

static e2_data_t g_e2;
static volatile bool g_new_e2;
static uint32_t g_e2_packets;
static uint32_t g_crc_errors;
static uint32_t g_last_e2_ms;
static bool g_compat_seen;
static bool g_compat_fix;
static uint8_t g_compat_major;
static uint8_t g_compat_minor;
static int32_t g_compat_latitude_microdegrees;
static int32_t g_compat_longitude_microdegrees;
static int32_t g_compat_altitude_decimeters;
static char g_compat_latitude_hemisphere;
static char g_compat_longitude_hemisphere;

static void gpio_config(uint32_t base, unsigned pin, uint32_t nibble)
{
    volatile uint32_t *cr = (volatile uint32_t *)((pin < 8u) ? (base + 0x00u) : (base + 0x04u));
    const unsigned shift = (pin & 7u) * 4u;
    uint32_t value = *cr;
    value &= ~(0xFu << shift);
    value |= (nibble & 0xFu) << shift;
    *cr = value;
}

static void clocks_and_gpio_init(void)
{
    RCC_APB2ENR |= (1u << 0) | (1u << 2) | (1u << 3);
    RCC_APB1ENR |= (1u << 17);

    /* Entradas dos encoders: pull-up. */
    gpio_config(GPIOA_BASE, 0u, 0x8u);
    gpio_config(GPIOA_BASE, 1u, 0x8u);
    gpio_config(GPIOB_BASE, 6u, 0x8u);
    gpio_config(GPIOB_BASE, 7u, 0x8u);
    gpio_config(GPIOB_BASE, 8u, 0x8u);
    gpio_config(GPIOB_BASE, 9u, 0x8u);
    GPIO_ODR(GPIOA_BASE) |= (1u << 0) | (1u << 1);
    GPIO_ODR(GPIOB_BASE) |= (1u << 6) | (1u << 7) | (1u << 8) | (1u << 9);

    /* USART2: PA2 TX AF push-pull; PA3 RX flutuante. */
    gpio_config(GPIOA_BASE, 2u, 0xBu);
    gpio_config(GPIOA_BASE, 3u, 0x4u);

    /* Saidas internas de estimulo para os encoders e pulsos Z. */
    for (unsigned pin = 10u; pin <= 15u; ++pin) {
        gpio_config(GPIOB_BASE, pin, 0x3u);
    }
    GPIO_ODR(GPIOB_BASE) &= ~((0x3Fu) << 10);
}

static void uart_init(void)
{
    /* 8 MHz / 115200 = 69,44. RXNE gera IRQ para nao perder pacote e2. */
    USART2_BRR = 69u;
    USART2_CR1 = (1u << 13) | (1u << 5) | (1u << 3) | (1u << 2);
    NVIC_ISER1 = 1u << 6; /* USART2 IRQ38 -> ISER1 bit 6. */
}

static void z_interrupts_init(void)
{
    AFIO_EXTICR3 = (AFIO_EXTICR3 & ~0xFFu) | 0x11u;
    EXTI_PR = (1u << 8) | (1u << 9);
    EXTI_RTSR |= (1u << 8) | (1u << 9);
    EXTI_IMR |= (1u << 8) | (1u << 9);
    NVIC_ISER0 = 1u << 23;
}

static void systick_init(void)
{
    SYST_RVR = 7999u;
    SYST_CVR = 0u;
    SYST_CSR = 7u;
}

static void uart_putc(char c)
{
    while ((USART2_SR & (1u << 7)) == 0u) {
    }
    USART2_DR = (uint32_t)(uint8_t)c;
}

static void uart_puts(const char *text)
{
    while (*text != '\0') {
        uart_putc(*text++);
    }
}

static void uart_put_u64(uint64_t value)
{
    char buffer[20];
    unsigned used = 0u;
    if (value == 0u) {
        uart_putc('0');
        return;
    }
    while ((value != 0u) && (used < sizeof buffer)) {
        buffer[used++] = (char)('0' + (value % 10u));
        value /= 10u;
    }
    while (used != 0u) {
        uart_putc(buffer[--used]);
    }
}

static void uart_put_u32(uint32_t value)
{
    uart_put_u64(value);
}

static void uart_put_i32(int32_t value)
{
    if (value < 0) {
        uart_putc('-');
        uart_put_u32((uint32_t)(-(value + 1)) + 1u);
    } else {
        uart_put_u32((uint32_t)value);
    }
}

static void uart_put_fixed(double value, unsigned decimals)
{
    static const uint32_t scales[] = {1u, 10u, 100u, 1000u, 10000u, 100000u, 1000000u};
    const uint32_t scale = scales[(decimals <= 6u) ? decimals : 6u];
    if (value < 0.0) {
        uart_putc('-');
        value = -value;
    }
    const uint64_t scaled = (uint64_t)(value * (double)scale + 0.5);
    const uint64_t integer = scaled / scale;
    uint64_t fraction = scaled % scale;
    uart_put_u64(integer);
    if (decimals != 0u) {
        uart_putc('.');
        uint32_t divisor = scale / 10u;
        while (divisor != 0u) {
            uart_putc((char)('0' + (fraction / divisor) % 10u));
            divisor /= 10u;
        }
    }
}

static void uart_put_fixed_i32(int32_t scaled_value, unsigned decimals)
{
    static const uint32_t scales[] = {1u, 10u, 100u, 1000u, 10000u, 100000u, 1000000u};
    const uint32_t scale = scales[(decimals <= 6u) ? decimals : 6u];
    uint32_t absolute;
    if (scaled_value < 0) {
        uart_putc('-');
        absolute = (uint32_t)(-(scaled_value + 1)) + 1u;
    } else {
        absolute = (uint32_t)scaled_value;
    }
    uart_put_u32(absolute / scale);
    if (decimals != 0u) {
        uart_putc('.');
        const uint32_t fraction = absolute % scale;
        uint32_t divisor = scale / 10u;
        while (divisor != 0u) {
            uart_putc((char)('0' + (fraction / divisor) % 10u));
            divisor /= 10u;
        }
    }
}

static void rx_push(uint8_t byte)
{
    const uint16_t next = (uint16_t)((g_rx_head + 1u) & (RX_BUFFER_SIZE - 1u));
    if (next != g_rx_tail) {
        g_rx_buffer[g_rx_head] = byte;
        g_rx_head = next;
    } else {
        ++g_rx_overflow;
    }
}

void USART2_IRQHandler(void)
{
    if ((USART2_SR & (1u << 5)) != 0u) {
        rx_push((uint8_t)USART2_DR);
    }
}

static bool rx_get(uint8_t *byte)
{
    if (g_rx_tail == g_rx_head) {
        return false;
    }
    *byte = g_rx_buffer[g_rx_tail];
    g_rx_tail = (uint16_t)((g_rx_tail + 1u) & (RX_BUFFER_SIZE - 1u));
    return true;
}

static uint16_t crc16_update(uint16_t crc, uint8_t byte)
{
    crc ^= (uint16_t)byte << 8;
    for (unsigned bit = 0u; bit < 8u; ++bit) {
        crc = (crc & 0x8000u) ? (uint16_t)((crc << 1) ^ 0x1021u) : (uint16_t)(crc << 1);
    }
    return crc;
}

static uint32_t read_u32_le(const uint8_t *src)
{
    return (uint32_t)src[0] |
           ((uint32_t)src[1] << 8) |
           ((uint32_t)src[2] << 16) |
           ((uint32_t)src[3] << 24);
}

static float read_f32_le(const uint8_t *src)
{
    union {
        uint32_t u;
        float f;
    } converter;
    converter.u = read_u32_le(src);
    return converter.f;
}

static uint32_t pair_shift_right(uint32_t high, uint32_t low, unsigned shift)
{
    if (shift == 0u) {
        return low;
    }
    if (shift < 32u) {
        return (low >> shift) | (high << (32u - shift));
    }
    if (shift < 64u) {
        return high >> (shift - 32u);
    }
    return 0u;
}

static uint32_t pair_bit(uint32_t high, uint32_t low, unsigned bit)
{
    if (bit < 32u) {
        return (low >> bit) & 1u;
    }
    if (bit < 64u) {
        return (high >> (bit - 32u)) & 1u;
    }
    return 0u;
}

static void multiply_u32(uint32_t a, uint32_t b,
                         uint32_t *product_high, uint32_t *product_low)
{
    const uint32_t a0 = a & 0xFFFFu;
    const uint32_t a1 = a >> 16;
    const uint32_t b0 = b & 0xFFFFu;
    const uint32_t b1 = b >> 16;
    const uint32_t p0 = a0 * b0;
    const uint32_t p1 = a0 * b1;
    const uint32_t p2 = a1 * b0;
    const uint32_t p3 = a1 * b1;
    const uint32_t middle = (p0 >> 16) + (p1 & 0xFFFFu) + (p2 & 0xFFFFu);

    *product_low = (p0 & 0xFFFFu) | (middle << 16);
    *product_high = p3 + (p1 >> 16) + (p2 >> 16) + (middle >> 16);
}

static int32_t read_f64_as_fixed_i32(const uint8_t *src, uint32_t scale)
{
    /*
     * Decodifica IEEE-754 binary64 para inteiro escalado usando apenas
     * uint32_t. Isso contorna as rotinas de 64 bits defeituosas do VSM.
     */
    const uint32_t low_word = read_u32_le(src);
    const uint32_t high_word = read_u32_le(src + 4);
    const bool negative = (high_word & 0x80000000u) != 0u;
    const uint32_t exponent_bits = (high_word >> 20) & 0x7FFu;

    if (exponent_bits == 0u) {
        return 0;
    }
    if (exponent_bits == 0x7FFu) {
        return negative ? -2147483647 : 2147483647;
    }

    const int exponent = (int)exponent_bits - 1023;
    if (exponent >= 31) {
        return negative ? -2147483647 : 2147483647;
    }
    if (exponent < -32) {
        return 0;
    }

    const uint32_t significand_high = (high_word & 0xFFFFFu) | 0x100000u;
    const uint32_t significand_low = low_word;
    const unsigned shift = (unsigned)(52 - exponent);
    uint32_t integer = 0u;
    uint32_t remainder_high = significand_high;
    uint32_t remainder_low = significand_low;

    if (shift < 53u) {
        if (shift >= 32u) {
            integer = significand_high >> (shift - 32u);
            const unsigned kept_high_bits = shift - 32u;
            remainder_high = (kept_high_bits == 0u)
                ? 0u
                : significand_high & ((1u << kept_high_bits) - 1u);
        } else {
            integer = (significand_high << (32u - shift)) |
                      (significand_low >> shift);
            remainder_high = 0u;
            remainder_low = significand_low & ((1u << shift) - 1u);
        }
    }

    uint32_t fraction_q32 = 0u;
    bool fraction_carry = false;
    if (shift <= 32u) {
        fraction_q32 = remainder_low << (32u - shift);
    } else {
        const unsigned q_shift = shift - 32u;
        fraction_q32 = pair_shift_right(remainder_high, remainder_low, q_shift);
        if ((q_shift != 0u) && pair_bit(remainder_high, remainder_low, q_shift - 1u)) {
            ++fraction_q32;
            if (fraction_q32 == 0u) {
                fraction_carry = true;
            }
        }
    }

    if (fraction_carry) {
        ++integer;
    }

    uint32_t product_high;
    uint32_t product_low;
    multiply_u32(fraction_q32, scale, &product_high, &product_low);
    const uint32_t rounded_low = product_low + 0x80000000u;
    const uint32_t fraction_scaled = product_high + (rounded_low < product_low ? 1u : 0u);

    if ((integer > (2147483647u / scale)) ||
        ((integer * scale) > (2147483647u - fraction_scaled))) {
        return negative ? -2147483647 : 2147483647;
    }

    const uint32_t scaled = integer * scale + fraction_scaled;
    return negative ? -(int32_t)scaled : (int32_t)scaled;
}

static void decode_e2(const uint8_t *payload)
{
    g_e2.timer_ms = read_u32_le(payload + 0);
    g_e2.roll = read_f32_le(payload + 12);
    g_e2.pitch = read_f32_le(payload + 16);
    g_e2.yaw = read_f32_le(payload + 20);
    g_e2.accel_x = read_f32_le(payload + 24);
    g_e2.accel_y = read_f32_le(payload + 28);
    g_e2.accel_z = read_f32_le(payload + 32);
    g_e2.gyro_x = read_f32_le(payload + 48);
    g_e2.gyro_y = read_f32_le(payload + 52);
    g_e2.gyro_z = read_f32_le(payload + 56);
    g_e2.vel_n = read_f32_le(payload + 72);
    g_e2.vel_e = read_f32_le(payload + 76);
    g_e2.vel_d = read_f32_le(payload + 80);
    g_e2.latitude_microdegrees = read_f64_as_fixed_i32(payload + 96, 1000000u);
    g_e2.longitude_microdegrees = read_f64_as_fixed_i32(payload + 104, 1000000u);
    g_e2.altitude_decimeters = read_f64_as_fixed_i32(payload + 112, 10u);
    g_e2.mode = payload[120];
    g_e2.linear_accel_switch = payload[121];
    g_e2.turn_switch = payload[122];
    ++g_e2_packets;
    g_last_e2_ms = g_ms;
    g_new_e2 = true;
}

static void decode_compat_position(const uint8_t *payload)
{
    g_compat_major = payload[0];
    g_compat_minor = payload[1];
    g_compat_fix = payload[2] != 0u;
    g_compat_latitude_microdegrees = (int32_t)read_u32_le(payload + 3);
    g_compat_longitude_microdegrees = (int32_t)read_u32_le(payload + 7);
    g_compat_altitude_decimeters = (int32_t)read_u32_le(payload + 11);
    g_compat_latitude_hemisphere = (char)payload[15];
    g_compat_longitude_hemisphere = (char)payload[16];
    g_compat_seen = true;
}

static void aceinna_parser_task(void)
{
    enum {
        WAIT_55_1,
        WAIT_55_2,
        READ_CODE_HI,
        READ_CODE_LO,
        READ_LENGTH,
        READ_PAYLOAD,
        READ_CRC_HI,
        READ_CRC_LO
    };
    static unsigned state;
    static uint16_t code;
    static uint8_t length;
    static uint8_t payload[192];
    static unsigned payload_index;
    static uint16_t crc;
    static uint16_t received_crc;
    uint8_t byte;

    while (rx_get(&byte)) {
        switch (state) {
        case WAIT_55_1:
            if (byte == 0x55u) {
                state = WAIT_55_2;
            }
            break;
        case WAIT_55_2:
            state = (byte == 0x55u) ? READ_CODE_HI : WAIT_55_1;
            break;
        case READ_CODE_HI:
            code = (uint16_t)byte << 8;
            crc = crc16_update(0x1D0Fu, byte);
            state = READ_CODE_LO;
            break;
        case READ_CODE_LO:
            code |= byte;
            crc = crc16_update(crc, byte);
            state = READ_LENGTH;
            break;
        case READ_LENGTH:
            length = byte;
            crc = crc16_update(crc, byte);
            payload_index = 0u;
            state = (length == 0u) ? READ_CRC_HI : ((length <= sizeof payload) ? READ_PAYLOAD : WAIT_55_1);
            break;
        case READ_PAYLOAD:
            payload[payload_index++] = byte;
            crc = crc16_update(crc, byte);
            if (payload_index >= length) {
                state = READ_CRC_HI;
            }
            break;
        case READ_CRC_HI:
            received_crc = (uint16_t)byte << 8;
            state = READ_CRC_LO;
            break;
        case READ_CRC_LO:
            received_crc |= byte;
            if (received_crc == crc) {
                if ((code == 0x6532u) && (length == 123u)) {
                    decode_e2(payload);
                } else if ((code == 0x6336u) && (length == 17u)) {
                    decode_compat_position(payload);
                }
            } else {
                ++g_crc_errors;
            }
            state = WAIT_55_1;
            break;
        default:
            state = WAIT_55_1;
            break;
        }
    }
}

static void stimulus_step(void)
{
    static const uint8_t forward[4] = {0u, 1u, 3u, 2u};
    static const uint8_t reverse[4] = {0u, 2u, 3u, 1u};
    static uint32_t step;
    uint32_t odr = GPIO_ODR(GPIOB_BASE);

    odr &= ~((0x3Fu) << 10);
    odr |= ((uint32_t)forward[step & 3u]) << 10;
    odr |= ((uint32_t)reverse[step & 3u]) << 12;
    if ((step % 128u) == 0u) {
        odr |= 1u << 14;
    }
    if ((step % 192u) == 0u) {
        odr |= 1u << 15;
    }
    GPIO_ODR(GPIOB_BASE) = odr;
    ++step;
}

static void encoder_software_sample(void)
{
    static const int32_t delta[16] = {
         0,  1, -1,  0,
        -1,  0,  0,  1,
         1,  0,  0, -1,
         0, -1,  1,  0
    };
    const uint32_t gpioa = GPIO_IDR(GPIOA_BASE);
    const uint32_t gpiob = GPIO_IDR(GPIOB_BASE);
    const uint8_t left = (uint8_t)((((gpioa >> 0) & 1u) << 1) | ((gpioa >> 1) & 1u));
    const uint8_t right = (uint8_t)((((gpiob >> 6) & 1u) << 1) | ((gpiob >> 7) & 1u));

    if (!g_encoder_sample_ready) {
        g_prev_left = left;
        g_prev_right = right;
        g_encoder_sample_ready = true;
        return;
    }
    g_encoder_left += delta[(g_prev_left << 2) | left];
    g_encoder_right += delta[(g_prev_right << 2) | right];
    g_prev_left = left;
    g_prev_right = right;
}

void SysTick_Handler(void)
{
    ++g_ms;
}

void EXTI9_5_IRQHandler(void)
{
    const uint32_t pending = EXTI_PR;
    if ((pending & (1u << 8)) != 0u) {
        ++g_z_left;
        EXTI_PR = 1u << 8;
    }
    if ((pending & (1u << 9)) != 0u) {
        ++g_z_right;
        EXTI_PR = 1u << 9;
    }
}

static void report_e2(void)
{
    const bool use_compat = g_compat_seen &&
                            (g_compat_major == 2u) &&
                            (g_compat_minor >= 5u);
    const int32_t latitude = use_compat
        ? g_compat_latitude_microdegrees : g_e2.latitude_microdegrees;
    const int32_t longitude = use_compat
        ? g_compat_longitude_microdegrees : g_e2.longitude_microdegrees;
    const int32_t altitude = use_compat
        ? g_compat_altitude_decimeters : g_e2.altitude_decimeters;

    uart_puts("E2=OK CRC=OK PKT=");
    uart_put_u32(g_e2_packets);
    uart_puts(" POS=");
    uart_puts(use_compat ? "COMPAT32" : "E2");
    uart_puts(" EMU=");
    if (g_compat_seen) {
        uart_put_u32(g_compat_major);
        uart_putc('.');
        uart_put_u32(g_compat_minor);
    } else {
        uart_puts("NA");
    }
    uart_puts(" HEM=");
    if (g_compat_seen) {
        uart_putc(g_compat_latitude_hemisphere);
        uart_putc(g_compat_longitude_hemisphere);
    } else {
        uart_puts("NA");
    }
    uart_puts(" MODE=");
    uart_puts((g_e2.mode == 4u) ? "INS" : "VG");
    uart_puts(" GPS=");
    uart_puts(use_compat ? (g_compat_fix ? "FIX" : "NOFIX")
                         : ((g_e2.mode == 4u) ? "FIX" : "NOFIX"));
    uart_puts(" LAT=");
    uart_put_fixed_i32(latitude, 6u);
    uart_puts(" LON=");
    uart_put_fixed_i32(longitude, 6u);
    uart_puts(" ALT=");
    uart_put_fixed_i32(altitude, 1u);
    uart_puts(" RPY=");
    uart_put_fixed(g_e2.roll, 2u);
    uart_putc(',');
    uart_put_fixed(g_e2.pitch, 2u);
    uart_putc(',');
    uart_put_fixed(g_e2.yaw, 2u);
    uart_puts(" ACC=");
    uart_put_fixed(g_e2.accel_x, 3u);
    uart_putc(',');
    uart_put_fixed(g_e2.accel_y, 3u);
    uart_putc(',');
    uart_put_fixed(g_e2.accel_z, 3u);
    uart_puts(" L=");
    uart_put_i32(g_encoder_left);
    uart_puts(" R=");
    uart_put_i32(g_encoder_right);
    uart_puts(" ZL=");
    uart_put_u32(g_z_left);
    uart_puts(" ZR=");
    uart_put_u32(g_z_right);
    uart_puts(" CAN=NA(PROTEUS)\r\n");
}

int main(void)
{
    uint32_t last_stimulus = 0u;
    uint32_t last_wait_report = 0u;
    clocks_and_gpio_init();
    uart_init();
    z_interrupts_init();
    systick_init();

    uart_puts("\r\nIMU_GPS_VALIDATION v2.6 ACEINNA E2\r\n");
    uart_puts("CLK=8MHz UART2=115200 ENC=SW CAN=NA(PROTEUS)\r\n");
    uart_puts("Aguardando U2/OpenIMU em PA3 e pacotes 0x5555 0x6532 LEN=123.\r\n");

    for (;;) {
        const uint32_t now = g_ms;

        if ((uint32_t)(now - last_stimulus) >= 2u) {
            last_stimulus += 2u;
            encoder_software_sample();
            stimulus_step();
        }

        aceinna_parser_task();

        if (g_new_e2) {
            g_new_e2 = false;
            report_e2();
        }

        if (((uint32_t)(now - g_last_e2_ms) >= 1500u) &&
            ((uint32_t)(now - last_wait_report) >= 1000u)) {
            last_wait_report = now;
            uart_puts("E2=WAIT CRC_ERR=");
            uart_put_u32(g_crc_errors);
            uart_puts(" RX_OVF=");
            uart_put_u32(g_rx_overflow);
            uart_puts(" Verifique U2.PA2 -> U1.PA3 e 115200 baud.\r\n");
        }

        /* Fallback caso o modelo VSM nao entregue a IRQ RXNE. */
        if ((USART2_SR & (1u << 5)) != 0u) {
            rx_push((uint8_t)USART2_DR);
        }
    }
}

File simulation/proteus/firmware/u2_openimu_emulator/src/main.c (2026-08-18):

#include <stdint.h>
#include <stdbool.h>

/*
 * Emulador de OpenIMU300ZI para o Proteus.
 *
 * Entrada:
 *   VGPS TX -> PA10 / USART1_RX, 9600 baud, NMEA 0183.
 * Saida:
 *   PA2 / USART2_TX -> U1 PA3, 115200 baud.
 *
 * A saida usa o pacote ACEINNA GPS/INS "e2" (codigo 0x6532), payload
 * oficial de 123 bytes e CRC16-CCITT (poly 0x1021, init 0x1D0F).
 */

#define REG32(addr) (*(volatile uint32_t *)(addr))

#define RCC_BASE        0x40021000u
#define RCC_APB2ENR     REG32(RCC_BASE + 0x18u)
#define RCC_APB1ENR     REG32(RCC_BASE + 0x1Cu)

#define GPIOA_BASE      0x40010800u
#define GPIO_ODR(base)  REG32((base) + 0x0Cu)

#define USART1_BASE     0x40013800u
#define USART1_SR       REG32(USART1_BASE + 0x00u)
#define USART1_DR       REG32(USART1_BASE + 0x04u)
#define USART1_BRR      REG32(USART1_BASE + 0x08u)
#define USART1_CR1      REG32(USART1_BASE + 0x0Cu)

#define USART2_BASE     0x40004400u
#define USART2_SR       REG32(USART2_BASE + 0x00u)
#define USART2_DR       REG32(USART2_BASE + 0x04u)
#define USART2_BRR      REG32(USART2_BASE + 0x08u)
#define USART2_CR1      REG32(USART2_BASE + 0x0Cu)

#define SYST_CSR        REG32(0xE000E010u)
#define SYST_RVR        REG32(0xE000E014u)
#define SYST_CVR        REG32(0xE000E018u)
#define NVIC_ISER1      REG32(0xE000E104u)

#define RX_BUFFER_SIZE  256u

static volatile uint32_t g_ms;
static volatile uint8_t g_rx_buffer[RX_BUFFER_SIZE];
static volatile uint16_t g_rx_head;
static volatile uint16_t g_rx_tail;
static volatile uint32_t g_rx_overflow;

static bool g_gps_valid;
static uint8_t g_gps_satellites;
static int32_t g_latitude_microdegrees;
static int32_t g_longitude_microdegrees;
static int32_t g_altitude_decimeters;
static char g_latitude_hemisphere = '?';
static char g_longitude_hemisphere = '?';
static uint32_t g_last_gga_ms;

static void gpio_config(uint32_t base, unsigned pin, uint32_t nibble)
{
    volatile uint32_t *cr = (volatile uint32_t *)((pin < 8u) ? (base + 0x00u) : (base + 0x04u));
    const unsigned shift = (pin & 7u) * 4u;
    uint32_t value = *cr;
    value &= ~(0xFu << shift);
    value |= (nibble & 0xFu) << shift;
    *cr = value;
}

static void clocks_gpio_uart_init(void)
{
    /* AFIO, GPIOA e USART1 no APB2; USART2 no APB1. */
    RCC_APB2ENR |= (1u << 0) | (1u << 2) | (1u << 14);
    RCC_APB1ENR |= (1u << 17);

    /* PA10 = USART1 RX flutuante; PA2 = USART2 TX AF push-pull. */
    gpio_config(GPIOA_BASE, 10u, 0x4u);
    gpio_config(GPIOA_BASE, 2u, 0xBu);

    /* 8 MHz / 9600 = 833,33. */
    USART1_BRR = 833u;
    USART1_CR1 = (1u << 13) | (1u << 5) | (1u << 2);

    /* 8 MHz / 115200 = 69,44. */
    USART2_BRR = 69u;
    USART2_CR1 = (1u << 13) | (1u << 3);

    /* USART1 e IRQ externa 37: ISER1 bit 5. */
    NVIC_ISER1 = 1u << 5;
}

static void systick_init(void)
{
    SYST_RVR = 7999u;
    SYST_CVR = 0u;
    SYST_CSR = 7u;
}

void SysTick_Handler(void)
{
    ++g_ms;
}

static void rx_push(uint8_t byte)
{
    const uint16_t next = (uint16_t)((g_rx_head + 1u) & (RX_BUFFER_SIZE - 1u));
    if (next != g_rx_tail) {
        g_rx_buffer[g_rx_head] = byte;
        g_rx_head = next;
    } else {
        ++g_rx_overflow;
    }
}

void USART1_IRQHandler(void)
{
    if ((USART1_SR & (1u << 5)) != 0u) {
        rx_push((uint8_t)USART1_DR);
    }
}

static bool rx_get(uint8_t *byte)
{
    if (g_rx_tail == g_rx_head) {
        return false;
    }
    *byte = g_rx_buffer[g_rx_tail];
    g_rx_tail = (uint16_t)((g_rx_tail + 1u) & (RX_BUFFER_SIZE - 1u));
    return true;
}

static void uart2_putc(uint8_t byte)
{
    while ((USART2_SR & (1u << 7)) == 0u) {
    }
    USART2_DR = byte;
}

static bool streq(const char *a, const char *b)
{
    while ((*a != '\0') && (*a == *b)) {
        ++a;
        ++b;
    }
    return *a == *b;
}

static uint8_t hex_value(char c)
{
    if ((c >= '0') && (c <= '9')) {
        return (uint8_t)(c - '0');
    }
    if ((c >= 'A') && (c <= 'F')) {
        return (uint8_t)(c - 'A' + 10);
    }
    if ((c >= 'a') && (c <= 'f')) {
        return (uint8_t)(c - 'a' + 10);
    }
    return 0xFFu;
}

static int32_t parse_i32(const char *text)
{
    int32_t value = 0;
    bool negative = false;
    if (*text == '-') {
        negative = true;
        ++text;
    }
    while ((*text >= '0') && (*text <= '9')) {
        value = value * 10 + (int32_t)(*text - '0');
        ++text;
    }
    return negative ? -value : value;
}

static int32_t parse_fixed_tenths(const char *text)
{
    bool negative = false;
    int32_t value = 0;
    int32_t tenth = 0;

    if (*text == '-') {
        negative = true;
        ++text;
    }
    while ((*text >= '0') && (*text <= '9')) {
        value = value * 10 + (int32_t)(*text - '0');
        ++text;
    }
    if (*text == '.') {
        ++text;
        if ((*text >= '0') && (*text <= '9')) {
            tenth = (int32_t)(*text - '0');
        }
    }
    value = value * 10 + tenth;
    return negative ? -value : value;
}

static __attribute__((noinline)) uint32_t divide_u32_by_60(uint32_t dividend)
{
    /* Divisao por 60 somente com comparacao, subtracao e soma. */
    uint32_t quotient = 0u;
    volatile uint32_t remainder = dividend;

    while (remainder >= 60000000u) { remainder -= 60000000u; quotient += 1000000u; }
    while (remainder >=  6000000u) { remainder -=  6000000u; quotient +=  100000u; }
    while (remainder >=   600000u) { remainder -=   600000u; quotient +=   10000u; }
    while (remainder >=    60000u) { remainder -=    60000u; quotient +=    1000u; }
    while (remainder >=     6000u) { remainder -=     6000u; quotient +=     100u; }
    while (remainder >=      600u) { remainder -=      600u; quotient +=      10u; }
    while (remainder >=       60u) { remainder -=       60u; quotient +=       1u; }
    return quotient;
}
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

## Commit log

2026-08-18 Add Proteus GPS/IMU functional validation
2026-09-09 feat: atualiza hardware GPS-IMU e bibliotecas KiCad
    [IMU.kicad_sch, IMU_board.kicad_pcb, IMU_board.kicad_sch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]
